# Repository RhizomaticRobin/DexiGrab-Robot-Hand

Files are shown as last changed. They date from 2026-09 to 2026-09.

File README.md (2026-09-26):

# DEXIGRAB

**/ˈdɛk.si.ɡræb/ (DEK-see-grab) - DEXIGRABs (plural): /ˈdɛk.si.ɡræbz/ (DEK-see-grabz)

An advanced, libre-source robot hand with integrated hybrid soft robotics, and soon GelSense-touch capabilities with pretrained sensor fusion RL models

robot hand
robot_hand_back

## Introduction

"What? Another esoteric 3D printed robot hand project that's basically just a toy/puppet/useless gizmo dohicky with 5 string motors? No! There's too many of those already!"

Well, here's where I might change your mind regarding that!

## Features

- **Flexible TPU palm mechanics**, allowing for hybrid soft robotics that allow for actual grasping around curved objects in comparison to current traditional robotic palm mechanics
- 20 motors allowing for **20 DOF hand dexterity**: 4 DOF for each finger and 4 on the thumb (yaw, pitch, base flexion, and a coupled middle/tip flexion). The V6 thumb-pitch motor is being added now.
- Straightforward 3D printing and assembly with **only 5-10 3D printed parts** to be assembled together for more plug-and-play use dynamics
- Mechanics and electronics **entirely constrained** inside the palm, allowing for full end-effector modularity with all current and future robotic manipulators
- Full integration of https://flexitac.github.io as NEW FULLY ENCOMPASSING TOUCH SENSING for the grand cost of... 2 dollars and 59 cents!
- **Universal Robot Attachment** system that can be 3D printed to interface with any robot arm's end effector attachment system
- **Multi-modal sensor fusion** integrating:
  - Intel® RealSense™ Depth Camera D455
  - (https://flexitac.github.io)
  - Arduino Pro Mini for motor encoder data collection

## V6 Hardware Redesign (in progress)

<p>
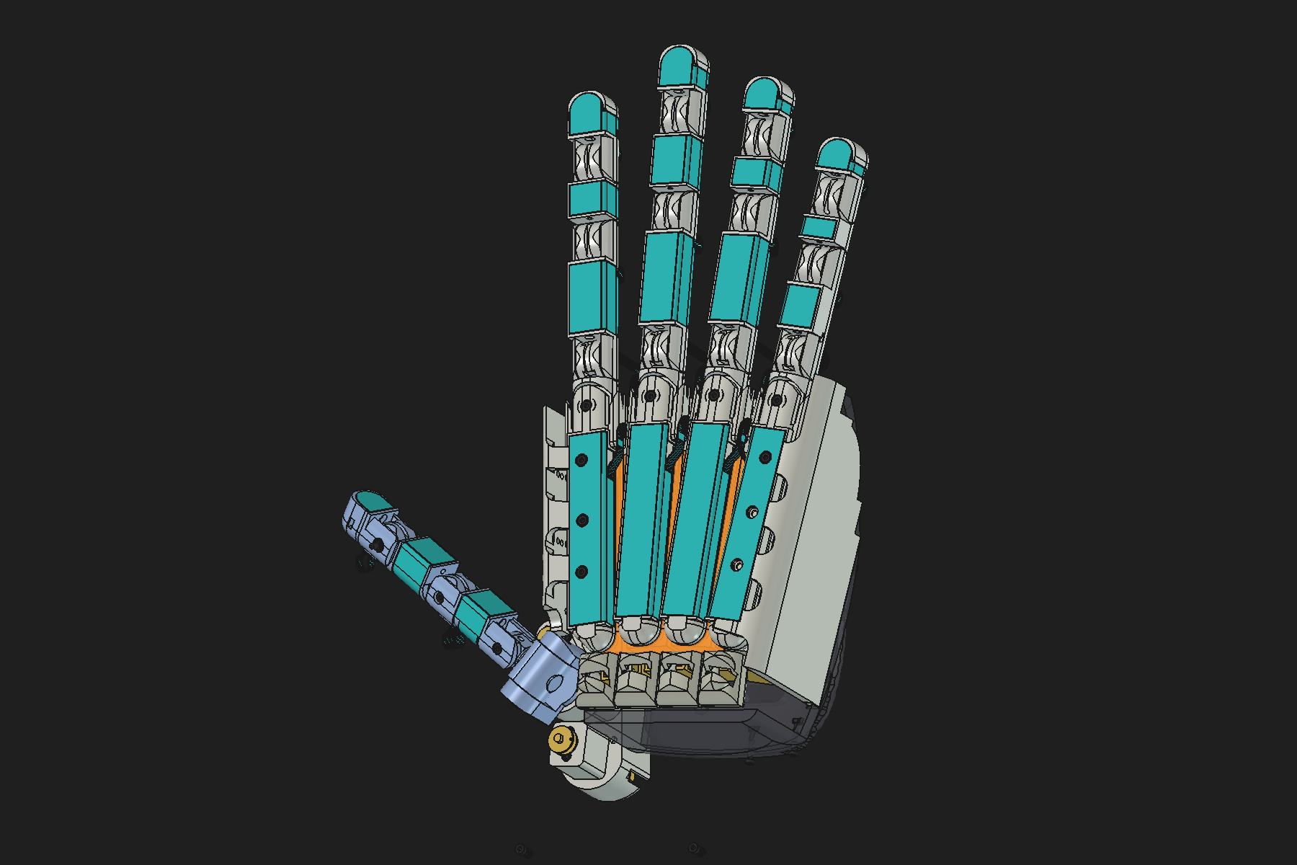
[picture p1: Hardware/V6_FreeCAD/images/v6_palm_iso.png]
V6 palm side

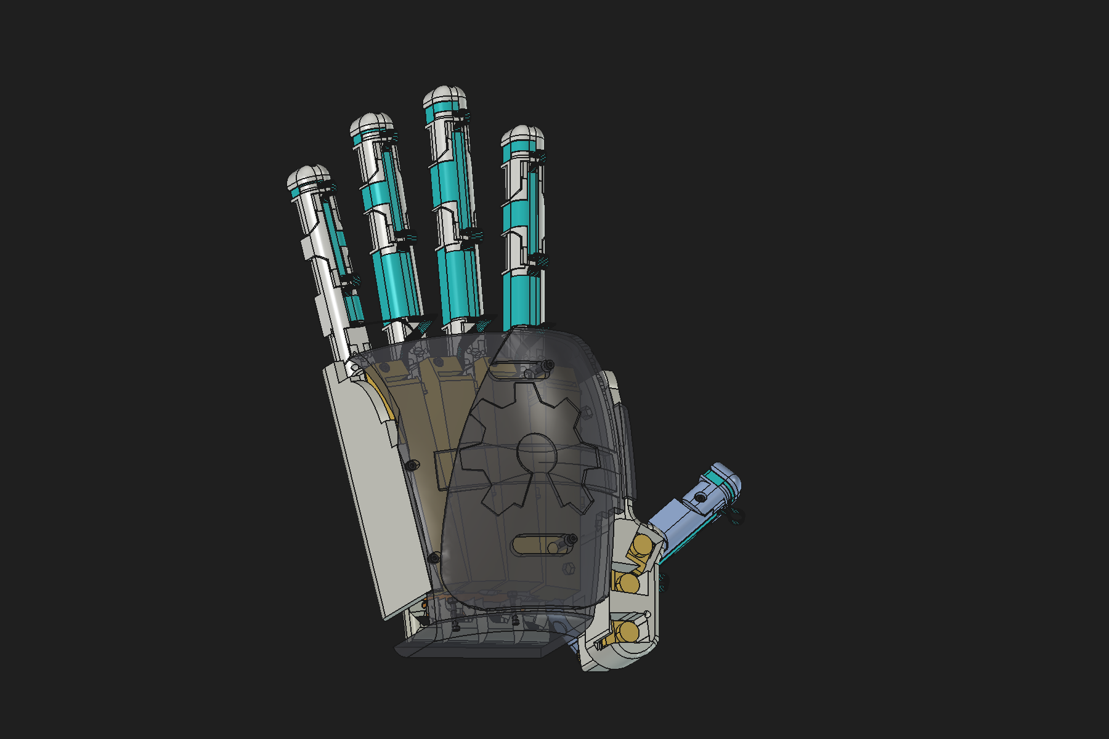
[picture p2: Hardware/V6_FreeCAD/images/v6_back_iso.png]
V6 back side

</p>

V6 is a full engineering pass over the V5 hand, rebuilt as a scripted, fully checked FreeCAD model. See [`Hardware/V6_FreeCAD/`](Hardware/V6_FreeCAD/).

- [x] **Straight N20 gearmotors with encoders** replace the discontinued worm motors, in a 2×2 magazine under each palm bone. There is room for every motor plug.
- [x] **J0 finger joint:** an M2 cap screw and nyloc nut replace the hammered rod that cracked about 35 % of parts.
- [x] **Palm bones:** PLA pillars through the flexible TPU palm, so the bones no longer split.
- [x] **Stronger thumb:**
  - a real yaw bearing, closed gimbal, and steel pins and bolts
  - opposition tuned from Leap Motion recordings
  - thumb motors seated and screwed into their original seat towers
- [x] **Palm shells** with spherical freedom and elastic O-ring retention.
- [x] **Full-hand [FlexiTac](https://flexitac.github.io) touch sensing:** 19 pads, 1421 taxels.
- [x] **Human-proportioned fingers:** Leap Motion bone lengths × 1.25.
- [x] **Fasteners and clearances:**
  - screws and nuts modelled (final validation pending)
  - 0.2 mm clearance wherever parts move
  - the global audit finds no moving pair under 0.2 mm
- [ ] **Electronics:**
  - 10 motor drivers inside the hand
  - a Mini Mega2560 PRO and 2× 6 V NiMH packs in a forearm pod
  - an auto-routed wiring harness
- [ ] **20th motor for thumb pitch**
- [ ] **V6.2:** resting pinky and index splay
- [ ] Final hardware validation and full range-of-motion audit

## AI & Simulation

simulated reach -> grasp -> lift with tactile pads

The simulation work now lives in this repo — see [`Simulation/`](Simulation/):

- **Full physics model of the hand in NVIDIA Newton** (MuJoCo-Warp solver): the flexible
  TPU palm modeled as 8 spring palm bones with 3 closed kinematic loops, 19 finger DOFs,
  self-colliding shells, and **15-pad tactile sensing**
- **Arm-mounted grasp demo** (Franka FR3) with an honest `--check` gate — a pass requires a
  clean approach, multi-pad tactile contact, and a real lift, not a cube wedged in the shell
- **GPU-batched in-hand reorientation RL environment** + self-contained PPO trainer,
  validated at **N=8192 parallel worlds, 0.0% solver divergence, ~47k env-steps/s** on a
  single RTX 5090 — plus the full forensics of the batched-solver NaN failure mode that had
  to be root-caused to get there
- **Honest RL status**: reorientation policies stall for contact-fidelity reasons documented
  in [`Simulation/README.md`](Simulation/README.md), so no pretrained models are published
  yet — that finding is what redirected this project toward engine-level contact-physics
  work, rather than shipping policies from a sim that can't be trusted

## Related Resources

- [L3-F-TOUCH shown](https://youtu.be/ASt3WRFcAxU?si=XV7Dn4dw2RqogxgP)
- [General Concept of touch module](https://youtu.be/qtQ4rK66vlE?si=lcGbKkfz59pFsFFY)
- [Simulation environment to be possibly integrated](https://github.com/facebookresearch/tacto)

## Applications

- Primary use as a **robotic end effector** with advanced grasping capabilities
- Secondary application as a **low-weight and cost-accessible hand for prosthetics design**, especially if built with worm drive gearboxes for human-level gripping strength
- Customizable socket system (hopefully also full copyleft) for any given person

## Project Details

- **<~$250 cost to build**
- **Fully open source hardware and software** under the GPL 3.0 and CERN-OHL pair license :)

## Coming Soon^TM

- Assembly instructions
- Component lists
- Software setup guide
- Simulation integration details
- Attachment system designs

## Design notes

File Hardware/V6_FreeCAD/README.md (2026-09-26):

# DexiGrab V6: FreeCAD redesign (work in progress)

V6 is a full engineering pass over the V5 hand. It keeps the V5 layout and the flexible TPU palm, and fixes what broke or was missing.

The model is built by a scripted FreeCAD pipeline, so every change is reproducible:
- Each workstream (J0 joint, palm pillars, thumb, motors, shells, tactile skin, finger proportions, fasteners) is one Python module that modifies the V5 parts.
- A headless build composes the modules.
- Every result is checked for clearance and range of motion.

<p>
V6 palm side
V6 back side
</p>

**Status (2026-09-26)**

- ✅ Built and verified in the model:
  - straight N20 motors
  - J0 screw joints and palm pillars
  - stronger thumb
  - palm shells
  - FlexiTac tactile skin
  - human-proportioned fingers
  - fasteners (final validation pending)
- ⏳ In progress:
  - electronics, battery pod and wiring harness
  - the 20th motor (thumb pitch)
  - V6.2 resting finger splay
  - final hardware validation and full audit

## Motors and degrees of freedom

| | Joints | Motors | Drive |
|---|---|---|---|
| **Each finger** (×4) | 4: J0 splay, J1 knuckle, J2 middle, J3 tip | 4 | A→J1, B→J2, C→J3 flexor tendons; D→J0 closed tendon loop (both ways). Every joint has its own motor. The fingers straighten on one elastic cord per joint. |
| **Thumb** | 6: R1 yaw, R2 pitch, R3 roll, R4 base flexion, R5 + R6 | 4 | T3 → yaw, direct drive. T4 → pitch, tendon loop *(being added)*. T1 → R4. T2 → R5 + R6, coupled by one tendon. Roll is passive (friction-held, −93…−23°). |
| **Hand** | **22** | **20** | **20 independently controlled DOF** |

The motors are straight (coaxial) N20 gearmotors with 6-pin Hall encoders; V5's worm GM12-N20 is no longer sold. The design assumes 1:298 gearing and 7 PPR, so measure your motors.

## What changed from V5

| V5 problem | V6 |
|---|---|
| J0: a hammered rod that cracked the part about 35 % of the time | M2×16 cap screw and M2 nyloc. The palm lug is thickened to 5 mm, with a flush counterbore, a hex nut pocket and 0.2 mm running gaps. The screw tip passes the nyloc by 3.5 threads. |
| The TPU palm insert splits each palm bone | PLA pillars through holes in the TPU. The TPU is inserted at a print pause, and every palm bone prints as one piece. |
| Weak thumb with a big gap | Real yaw bearing: Ø18 journal plus thrust ring, so the motor carries torque only. Closed gimbal, steel pin and tube at R2, M2 bolts at R4–R6. Flex stack re-clocked for opposition from Leap Motion data: pad-direction error 48.5° → 0.1°. |
| Worm motors discontinued; index and pinky motors had no room for their wires | A 2×2 N20 magazine under each palm bone. Every motor plug faces sideways into free space. |
| Thumb motors | T1 and T2 stand in their V5 seat towers, centred, turned to the seat angle and screwed to a printed floor. T3 direct-drives the yaw. |
| Palm shells | Shell2 rides on a spherical land on Shell1. Studs run through arc slots and are held by silicone O-rings: elastic retention with spherical freedom. |
| No touch sensing | [FlexiTac](https://flexitac.github.io) skin: 19 pads and 1421 taxels at 2 mm pitch. One flex circuit per finger, with slack loops at the joints. |
| Proportions | Fingers re-proportioned to the author's hand (Leap Motion bone lengths × 1.25). |
| Missing hardware | Screws, nuts, washers and heat-set inserts are modelled and placed from per-module requests, and checked by a validator. A final validation pass is pending. |
| Clearances | 0.2 mm per side wherever parts move or fit together. |

<p>
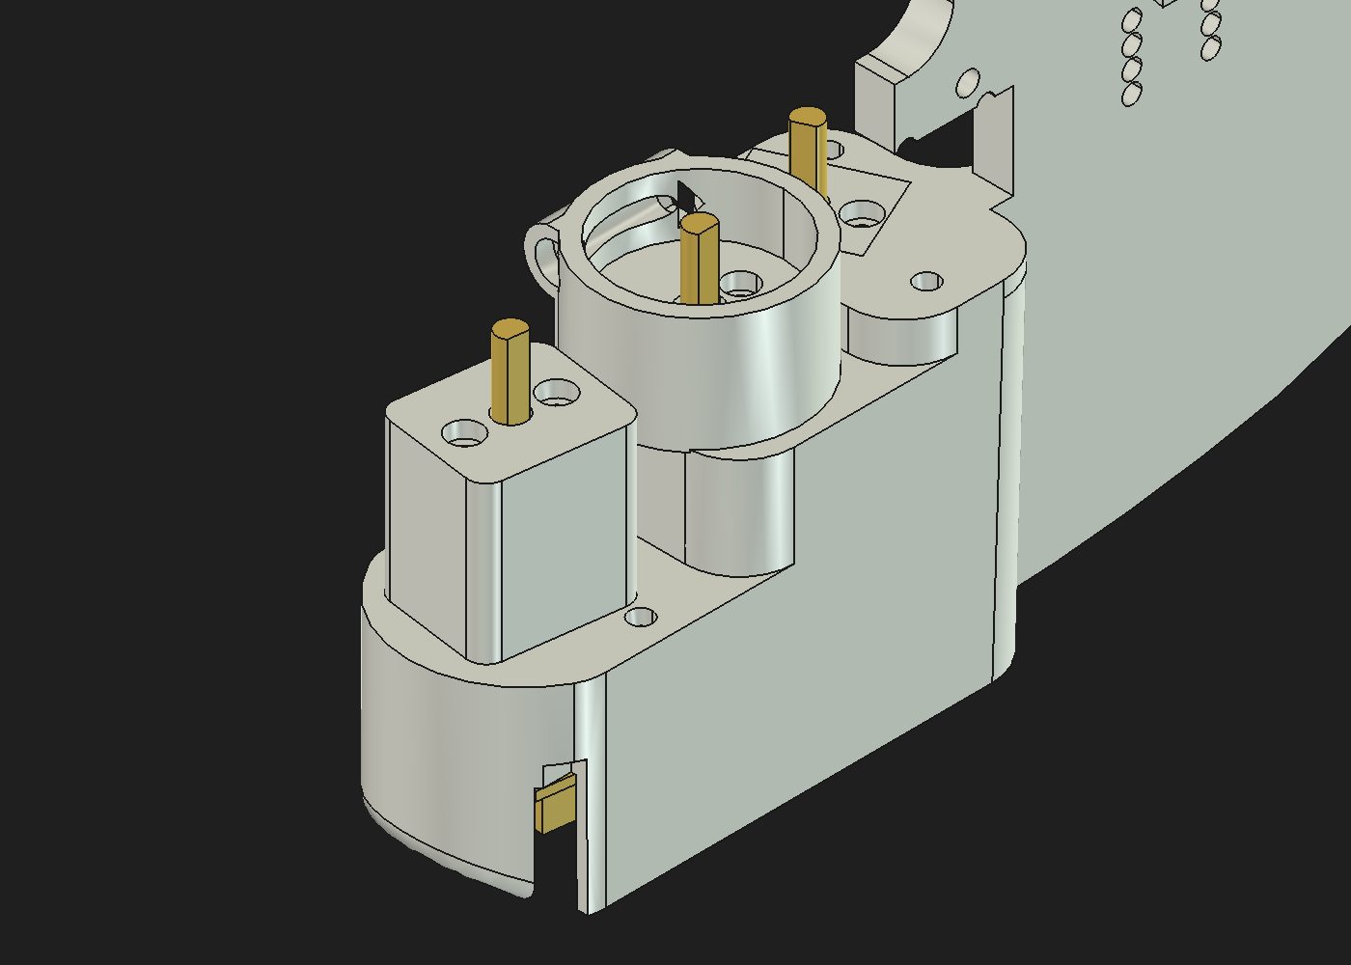
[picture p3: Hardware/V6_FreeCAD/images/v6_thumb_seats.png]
Thumb motor seats: T1 collar, T3 yaw turret, T2 floor

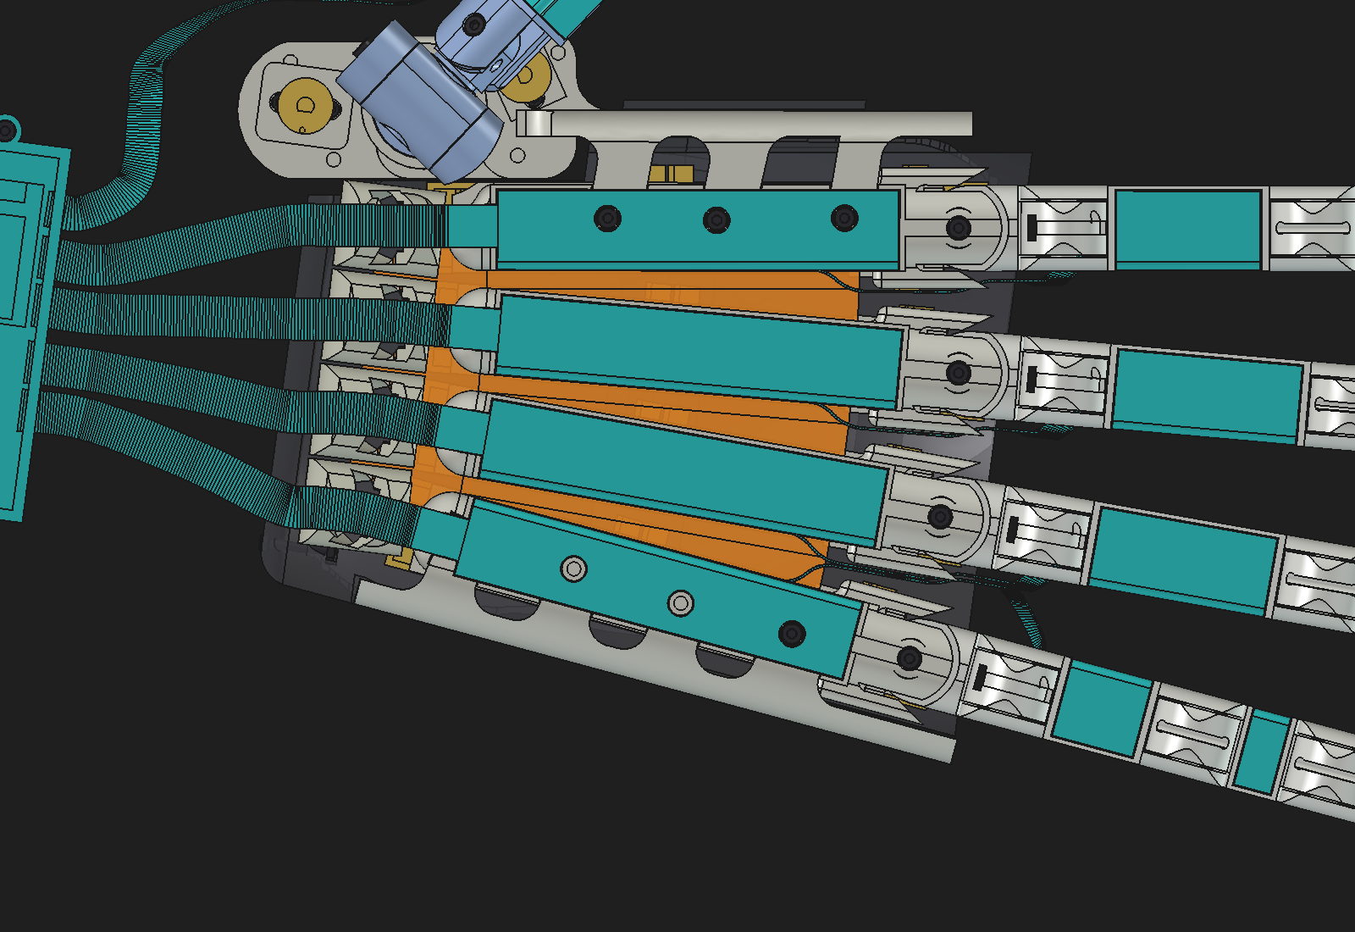
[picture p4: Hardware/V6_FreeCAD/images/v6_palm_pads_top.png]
Palm-side FlexiTac pads

</p>

## Verification highlights

**Global clearance audit**
- Zero moving part pairs are under 0.2 mm.
- The only volume overlaps are intended ones: self-tapping screws in their pilot holes, and heat-set inserts.

**Range-of-motion sweep of all 22 joints**
- Fingers J1–J3 are clear over 0–90°.
- Coupled limits for the firmware:
  - A finger meets its neighbour at about 11° of J0 splay.
  - Thumb yaw is clear on −85…−20° at pitch 0, and on the full −85…+75° at pitch ≤ −45°. The pitch motor makes that usable.

**Thumb**
- All running clearances are ≥ 0.2 mm.
- Index and middle pinch pads meet with gaps of 0.11 mm and 0.06 mm, with no other collisions.

**Motors and tendons**
- No motor or spool overlaps; every plug keep-out is clear.
- Tendon channel walls are ≥ 1.0 mm, and bends are ≥ 3 mm radius.

**Shells**
- 48/48 checks pass.
- A 25-pose roll/tilt sweep shows no collision and no loss of retention.

**Tactile**
- Pads sit 0.2 mm proud with 0.2 mm edge clearance.
- 60 finger poses are clear, and every flex bend is ≥ 3 mm radius.

Details, numbers and open items are in [`freecad/notes/V6_REPORT.md`](freecad/notes/V6_REPORT.md), with one note per workstream in [`freecad/notes/`](freecad/notes/).

## In progress

- **Electronics**
  - 10 dual H-bridge drivers on a deck inside Shell1.
  - An I/O board on cover_back.
  - A forearm pod holding the Mini Mega2560 PRO and the two 6 V 2800 mAh NiMH packs, wired in parallel.
  - An auto-routed harness and wiring tunnels.
- **T4 thumb-pitch motor** (the 20th motor): a tendon loop from a motor fixed in the thumb-side cover to a pulley on the pitch axis. It uses the spare driver channel.
- **V6.2:** a built-in resting splay, pinky outward and index toward the thumb, fitted to Leap Motion data.
- **Final checks:** hardware validation, then the full audit and range-of-motion sweep on the complete build.

## Folder layout

```
Hardware/V6_FreeCAD/
├── freecad/DexiGrab_V6.FCStd   the current V6 model (open it in FreeCAD 1.1)
├── freecad/lib/                one module per workstream: mod_j0, mod_pillars, mod_thumb, mod_actuation,
│                               mod_shells, mod_fixes, mod_tactile, mod_proportions, mod_hardware
│                               (+ n20.py motor model, partkeys.py, v6geom.py)
├── freecad/scripts/            build_v6.py (headless build), gui_load.py / gui_colors.py (load into the GUI),
│                               audit_clearance.py, rom_sweep.py, verify_<topic>.py
├── freecad/notes/              design notes per workstream, V6_REPORT.md, V5_CAD_analysis.md
├── freecad/regions/            motor poses, fastener requests, hardware report, space claims (JSON)
├── freecad/work/shells/bake/   baked Shell2 mesh data read by mod_shells
├── data/                       assembly transforms, joint definitions, V5 CAD analysis tables
├── v5_step/                    V5 part STEP export (pipeline input)
└── images/
```

## Open and rebuild

To just look at the model, open `freecad/DexiGrab_V6.FCStd` in FreeCAD 1.1.

To rebuild it:

1. **Point the scripts at your checkout.** They use absolute paths, which ship as a placeholder:

   ```bash
   cd Hardware/V6_FreeCAD
   python3 - <<'EOF'
   import pathlib
   root = pathlib.Path('.').resolve()
   PH = '/path/to/DexiGrab-Robot-Hand/Hardware/V6_FreeCAD'
   for p in root.rglob('*'):
       if p.is_file() and p.suffix in ('.py', '.sh', '.json', '.md'):
           s = p.read_text()
           if PH in s:
               p.write_text(s.replace(PH, str(root)))
   EOF
   ```

2. **Build every part headless**, which takes about 5 minutes. `freecadcmd` ships with FreeCAD; on macOS it is `/Applications/FreeCAD.app/Contents/Resources/bin/freecadcmd`.

   ```bash
   V6_RUN=1 V6_OUT=$PWD/freecad/work/built.FCStd V6_BREP=$PWD/freecad/build \
       freecadcmd freecad/scripts/build_v6.py
   ```

   `V6_MODULES=j0,pillars,...` selects and orders the modules; the default is all of them.

3. **Load the build into the GUI.** Open `freecad/DexiGrab_V6.FCStd`, then run `freecad/scripts/gui_load.py` and `freecad/scripts/gui_colors.py` from the Python console.

4. **Check it.** Each script takes the built file as `V6_IN=freecad/work/built.FCStd`:
   - `freecad/scripts/audit_clearance.py`
   - `freecad/scripts/rom_sweep.py`
   - `freecad/scripts/verify_<topic>.py`

The source parts are the V5 "simulacra" assembly, exported from Onshape with its exact occurrence transforms (`data/top_assembly_definition.json`).

## Licences

- The V6 files follow this repository's licences: CERN-OHL-W v2 for hardware and GPL-3.0 for software.
- The tactile skin reuses [FlexiTac](https://flexitac.github.io)'s readout board and firmware unchanged. FlexiTac is CC BY-NC 4.0 (non-commercial, attribution required), and that applies to any FlexiTac-derived parts you build.

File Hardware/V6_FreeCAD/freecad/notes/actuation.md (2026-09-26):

# Actuation (V6): straight N20 gearmotors, motor magazines, spools and tendons

Module `lib/mod_actuation.py`. Check `scripts/verify_actuation.py` (results in section 9). Published data:
`regions/actuation_motors.json` (world pose of all 19 motors incl. T3 from mod_thumb), `regions/actuation.json`
(claimed regions), `regions/fasteners_actuation.json`. Test build: `V6_MODULES=j0,pillars,thumb,actuation`
(about 3 min, one freecadcmd), then `freecadcmd scripts/verify_actuation.py`.

## 1. Why the V5 seats could not be reused

The V5 seats hold a worm GM12-N20 inclined 30.7° with its can in the palm bone and its perpendicular output shaft
(and the Ø21 pulley) hanging into the cavity. A straight N20 puts the spool on the motor axis, so:

- **In the old seat, the encoder end sits inside the bone.** The 6-pin plug mates along the axis, so its 8 mm plug
  space would point up through the palm face. That is exactly the "no room for the wiring" the user saw on the
  index and pinky; on the middle and ring it only looked better because the cable could escape sideways.
- **Reversed in the old seat**, the spool ends up inside the bone and its tendon leaves the spool at 60° down.
- **Vertical motors** (axis along the old worm shaft) need about 50 mm of depth each and fill the whole bowl.

## 2. Layout chosen: one 2×2 magazine under every palm bone

Each finger's four motors lie **along its own palm bone** (bone-local x), in two tiers:

| motor | tier | joint | spool (tendon axis radius) | notes |
|---|---|---|---|---|
| A | 1 (under the bone), front | **J1** flexor | small, r 3.75 | encoder toward the fingertips |
| B | 1, rear | **J2** flexor | small, r 3.75 | |
| C | 2 (under tier 1), front | **J3** flexor | big, r 5.65 | index C: tab turned to −z |
| D | 2, rear | **J0** loop (2 grooves) | big, r 5.65 | |

- **Why per finger:** the palm bones float on TPU (the palm arches). With every motor, spool and guide on the bone it
  drives, the tendon path from spool to finger never changes when the palm deforms. It also keeps the side walls free
  for the driver boards.
- **Orientation:** motor axis along the bone, flats vertical, encoder end toward the fingertips, PCB tab and plug toward
  bone-local +z (the thumb side). The index C motor has its tab toward −z because its +z plug space touched Shell1.
  - Every plug therefore points into the open inter-finger gap beside the magazine, 6–11 mm off the motor axis. Its
    cable drops straight down to the harness.
  - The adjacent finger's magazine is on the other side of that gap, and no two tabs face each other in the same gap.
- **Magazine:** PLA fused to the underside of the palm bone. It is printed as part of the bone (section 8).
  - Bays open downward. Each gearbox sits between two 0.6/0.8 mm **fork ribs** (a U-slot for the boss, and the can
    profile behind), which fix it axially and against the motor torque.
  - Two 1 mm **side lanes** run beside tier 1, and there is a 1.7 mm wall with the J0 tunnels in it. Roof strips
    (y 3.6–5.2, cut round the TPU peg holes) close the tunnels where the bone's rounded corners are thin (pinky).
  - An **under-J0 guide block** sits in front of motor A, below the J0 nut. A descent boss over A's magnet carries the
    A/B drops.
  - Near J0 the magazine stays out of the base-bone tongue's ±15° sweep: the slot floor is at y 4.7 (the j0 back-lug
    face), the cheeks under the wing channels are at |z| ≥ 6.95 for x > 83.1, and only the unused rear of the slot
    (x 81.5–83.2) is filled.
- **Tray:** a new part per finger (`actuation_tray_<finger>`).
  - It holds tier 2 in its own fork ribs, and its shelves carry the tier-1 gearboxes (0.2 mm gaps).
  - It hooks into a groove in the rear wall of the magazine and is held at the front by **1× M2×12 SHCS + M2 hex
    nut**. The nut is side-loaded into the guide block, below its tendon channels, and the head is recessed 6 mm
    in the tray.
  - The tray's front-bottom edge is chamfered to clear Shell1.
- **Old worm seats are filled.** This covers the troughs and the palm-face crescents, inside the 15×15 envelope for
  x 7.8–71.2. The fill stops **exactly at the TPU insert layer (y 0.5 and 1.1)**. It leaves every TPU peg hole and the
  index bracket-screw keep-outs open.
  - The TPU motor windows inside the layer are **left empty**. They are pillars' to fill if they want large pillars
    there.
  - The pillars stay ≥ 6.4 mm from every motor envelope, according to pillars.
- **Depth:** tier 1 is at world z −8.2 … −20.2, tier 2 at −21.6 … −33.6, and the tray floor bottom at about −35.6.
- **Bone-local x positions of the gearbox faces:** A 55.0, B 14.0, C 53.5, D 9.0. The motors run from x −1.8 (D shaft
  tip) to 85.0 (A magnet), and the tray from −3.6 to 94.4.
  - The magazines sit between world x ≈ −165 (the D shaft tip) and the knuckles. They stay behind the J0 nut
    keep-out and the metacarpal's J1 sweep.

## 3. Motor, spools, torque and speed

**Assumed motor:** 6 V N20, **1:298** (about 100 rpm no-load at 6 V), with a magnetic Hall encoder (7 PPR per channel).
- Stall torque ≈ 0.4 N·m; safe continuous ≈ 0.18 N·m (gearbox-limited).
- These are catalogue values. Measure the real ratio and stall current with BUILD_PLAN 1.6–1.8.
- 1:298 was chosen because the spur gearbox is back-drivable, unlike the V5 worms, and the highest common ratio gives
  the most holding friction and torque. Speed is still ample.

| spool | tendon radius | tendon force (continuous / stall) | tendon speed |
|---|---|---|---|
| small (A, B, T1, T2) | 3.75 mm (groove floor Ø7.0, flanges Ø9.8) | 48 N / 107 N | 39 mm/s |
| big (C, D) | 5.65 mm (floor Ø10.8, flanges Ø13.2) | 32 N / 71 N | 59 mm/s |

The groove radius is a trade-off:
- **Torque:** smaller is better.
- **Hub wall:** the hub needs at least 1.75 mm of wall around the Ø3 D-shaft, so the minimum floor radius is 3.25 mm.
- **Bend ratio:** D/d = 15 for 0.5 mm line.
- **Excursion:** the J3 flexor needs 33 mm, which is 0.9 turn on the big spool; the 2.4 mm groove holds about 4 turns.

Tier 2 needs the big radius so that its tendons clear tier 1 in the side lanes. It therefore drives the two
lowest-load joints, J3 and J0.

Resulting joint capability (continuous, no-load speed):

| joint | moment arm | torque | speed |
|---|---|---|---|
| J1 | 6.65 mm (tendon in a groove over the J1 head, constant) | 0.32 N·m | 336 °/s |
| J2 | 4.7 → 8.8 mm (open-roof knuckle, grows with flexion) | 0.23 → 0.42 N·m | 475 → 255 °/s |
| J3 | 4.7 → 8.8 mm | 0.15 → 0.28 N·m | 720 → 385 °/s |
| J0 | about 11 mm (lateral wing channels, antagonistic) | 0.35 N·m | 310 °/s |

At the continuous rating that is roughly 4–5 N of fingertip force with the finger straight, and more when the finger
is curled.

**Encoder:** 8344 counts per spool turn (7 × 4 × 298). That is 0.024° of J1 per count, or about 0.05° of J3.

**D-bore fit:** Ø3.0 nominal with the flat 1.0 mm from the axis, zero allowance on purpose. FDM holes print about
0.1 mm small, so the spool presses on.
- Torque is carried by the flat (form lock), not by friction.
- The flat contact stress at 0.18 N·m is about 14 MPa, and about 32 MPa at stall, against about 60 MPa for PLA.
- If the spool is too tight, ream it with a 3.0 mm drill. Add a drop of CA only if it walks off the shaft.
- A set screw does not fit: the smallest screw in the kit is M2×5, whose head would stand beyond the flange.

**Tendon anchor on the spool:** an axial Ø1.0 hole through the outer flange of each groove. The tendon is knotted
behind it.

## 4. Flexor-only drive for J1–J3, antagonistic loop for J0

**Bidirectional loops on J1–J3 are not usable with this knuckle geometry.**
- The back side of every knuckle is square: it is the hyperextension stop.
- An extensor through the V5 back channel (z −4.6) therefore lengthens by 12.3 mm over 90°, while the flexor shortens
  by 10.4–11.2 mm.
- A loop gains about 1–2 mm per joint, which is about 5 mm across J1–J3 for the J3 loop. UHMWPE stretches about 3 %,
  so the loop would over-tension and pull the anchors out.

**So each joint gets one flexor, and extension is passive.**
- Use one elastic per joint through the V5 back channels (z −4.6, added to every bone). A suggested cord is 1 mm
  silicone or latex, knotted, stiffer toward the palm: J1 > J2 > J3, so every flexor stays taut.
- Joint angles are set by the flexor lengths through the coupling matrix: flexor k shortens by the sum of its moment
  arms over the joints it crosses.

**J0 uses one spool with two grooves.** Its two ends run in mirror-image paths to the lateral wings. The loop length
changes only to second order, less than 0.3 mm at ±15°.

## 5. Tendon routing (0.5 mm braided UHMWPE, channels Ø1.2, bends R ≥ 3 except where stated)

**Palm bone and magazine (bone-local):**
- **A and B** rise from their spools through bend bosses (R 3) into two lanes in the bone's back half, at y 5.8 and
  z ∓1.6. The lanes run below the pillars and TPU pegs with at least 1 mm of wall.
- At x ≈ 81–88 they descend through the filled rear of the J0 slot and the boss over A's magnet. They pass beside the
  J0 nut, 4.3 mm off the centre plane, drop through the guide-block legs, and turn in under the nut.
- **C** rises beside tier 1 in the −z side lane, at y 14.0, and enters the guide block at the front, below the A/B
  drops.
- **The J0 axis is crossed underneath.** The guide exit is 4.3 mm in front of the J0 axis and the base-bone entry is
  12.8 mm in front, so the flexor length changes by less than 0.2 mm at ±15° of abduction. This is decoupled without
  touching the M2 J0 screw, which occupies the axis.
- **D (J0 loop):** the two ends rise at z ±5.65 and jog out into tunnels in the magazine wall (y 5.9, z ±6.3; y 6.8 under the TPU wrist-plate
  pocket for x < 9.5). They run forward to x 71.2, then ramp (via x 74.5, y 3.9) into the existing V5 lateral wing
  channels (Ø1.5), 20 % of the way along. They exit at the wing notches, ±10.5 mm lateral and 5.4 mm in front of the
  J0 axis.
  - The V5 wing channel is kept where V5 put it. Over x 82.5–83.5 it is already open into the J0 tongue slot in the
    j0 input (section 10).

**Base bone:**
- The three flexors enter from below at base-local x 13, the V5 connector position, 5.5 mm behind the J1 bore.
- They rise in a 1.4 × 4.4 slot and wrap the J1 head in a groove (floor R 6.4, 2.4 wide) down to the metacarpal's
  clevis floor.
- The J0 loop ends go to two knot anchors: a lateral Ø1.2 through-hole at x 16.8 and z −2, with Ø2.6 knot pockets
  from below at y ±4.4.

**Finger bones.** The same features go on the thumb's metacarpal, proximal and distal (mod_thumb's new keys).
- **The V5 Ø2 channels** are added from `data/sw_bone_channels.csv` (cut at Ø2.1 so they do not coincide with
  existing ones). This covers the metacarpal and pinky metacarpal, and all proximals and the distal at z +4.7/−4.6.
  The distal also gets its seven tip channels.
- **The V5 distal M1.6 anchor** is taken from `sw_instances.csv` (Mirrorm1_*): a Ø3.84 counterbore from the tip, a
  Ø2.1 hole x 5.3–13.3, an M1.6 nut pocket at x 6.5–8.3, and the side slot for the nut.
- **Found and fixed: the V5 palm channels reverse the flexor.**
  - The V5 channels run through the knuckle tongues past the joint axis. At J1 and J2 the flexor's line of action then
    crosses the axis after about 8° of flexion and the "flexor" extends the joint.
  - Fix: at J2 and J3 the channel roof is opened (a 1.6 mm slot down to z 4.0) from the tongue end to 7.7 mm past the
    axis. The effective exits are then the two clevis floors, ±7.7 mm from the axis.
  - The moment arm now grows from 4.7 to 8.8 mm over 90°, and the reversal angle is 117°.
  - At J1 the tendon wraps the head (above).
- **Knot pockets** (Ø3 from the palm face, x 19) anchor the J1 flexor in the metacarpal and the J2 flexor in the
  proximal. The J3 flexor ends at the distal's M1.6 clamp. Channel entries at the clevis floors are flared (Ø4 → Ø2.1).

**Thumb.**
- T1 (R4 flexor, anchored in the thumb metacarpal's knot pocket) and T2 (R5 + R6 flexor, anchored at the thumb
  distal's M1.6 clamp) stand in their V5 seat towers on cover3. Each tower has a 13.0 × 10.5 gearbox pocket, turned
  at its own angle.
- **Re-seated (orchestrator, 2026-09-26).** The first version stood T1/T2 square to the world axes, about 0.4 mm off
  their pocket centres. T1 floated 14 mm above its tower with no floor, and T2's floor and M1.6 holes fell inside the
  V5 pocket's open top. Now:
  - **T1** is centred on its pocket at (−186.02, 21.09) and turned −7.56°, gearbox face at z −24.2. Its tower is
    extended by a collar (pocket + 1.6 wall, R2 corners) from the tower top at z −38.6 to the floor top at z −21.4.
  - **T2** is centred at (−147.93, 26.52) and turned −65.56°, face at −25.8. The tab and plug point toward T3
    (0.3 mm to T3's body), so they stay inside cover3's outline. Turned the other way, the plug would break through
    the outer wall. The pocket's open top is filled from the face up to the tower top at z −23.1: that is its floor.
- The shaft stays below z −15.0 and within r 7.1, per the thumb agent.
- Both have their shaft up, the spool 2 mm out on the shaft above a 2.8 mm floor, and the gearbox face screwed with
  the N20's own 2× M1.6×3 SHCS. Each head sits in a Ø3.6 × 1.8 counterbore with 0.8 mm of floor under it. The spool
  well and tendon window keep their world orientation, so the tendon hand-off is unchanged.
- Their tendons leave the spools horizontally, at z ≈ −17 / −18.8.
- **Hand-off:** these tendons go to the thumb agent's Ø2 path along R2 (the steel tube), the roll-shaft cross holes and
  the ±15° barrel slots. The segment from the spools up to the R2 tube is **not modelled**: see open questions.

## 6. Motor / joint map for the firmware

`wind_sense` is the spool rotation, right-handed about the motor's +X (toward the encoder), that actuates the joint:
it winds the flexor in, or for D it turns J0 toward +Y world (the thumb side). The motor lead polarity that produces it
has to be recorded per channel on the bench, because it depends on the M1/M2 wiring. Channel numbers are a proposal:
the electronics agent owns the driver assignment. The same map is machine-readable in `regions/actuation_motors.json`
(`seat`, `joint`, `channel_proposal`, `wind_sense`, `spool_tendon_radius_mm`, `tendon_anchor`, and the world pose,
connector and plug keep-out of every motor).

| ch | seat | finger / joint | spool r | wind_sense | tendon anchor |
|---|---|---|---|---|---|
| 0 | ID | index J0 (loop) | 5.65 | −1 | base-bone side knots |
| 1 | IA | index J1 flexor | 3.75 | +1 | metacarpal knot pocket |
| 2 | IB | index J2 flexor | 3.75 | −1 | proximal knot pocket |
| 3 | IC | index J3 flexor | 5.65 | +1 | distal M1.6 clamp |
| 4–7 | MD, MA, MB, MC | middle J0, J1, J2, J3 | same | same | same |
| 8–11 | RD, RA, RB, RC | ring J0, J1, J2, J3 | same | same | same |
| 12–15 | PD, PA, PB, PC | pinky J0, J1, J2, J3 | same | same | same |
| 16 | T1 | thumb R4 flexor | 3.75 | +1 | thumb metacarpal knot pocket |
| 17 | T2 | thumb R5+R6 flexor | 3.75 | −1 | thumb distal M1.6 clamp |
| 18 | T3 | thumb R1 yaw, direct drive | none | n/a | mod_thumb coupler |

**Coupling.** With θ in rad, the flexor lengths are:
- L_A = L_A0 − 6.65·θ1
- L_B = L_B0 − 6.65·θ1 − r2(θ2)·θ2
- L_C = L_C0 − 6.65·θ1 − r2·θ2 − r3·θ3

where r2 and r3 grow from 4.7 to 8.8 mm with flexion (chord geometry, `tendon_paths` + the knuckle slots). J0 couples
into the flexors by less than 0.2 mm.

## 7. Tendon lengths and excursions (index; the others are within a few mm)

| tendon | path (spool → anchor) | approx. length | excursion for 0 → 90° | spool turn |
|---|---|---|---|---|
| A (J1) | palm 55 + under-J0 10 + base 24 + metacarpal 4 | 93 mm | 10.4 mm (J1) | 159° |
| B (J2) | palm 96 + 10 + 24 + metacarpal 17 + J2 span 15 + proximal 4 | 166 mm | 21.6 mm (J1 + J2) | 330° |
| C (J3) | palm 64 + 10 + 24 + 17 + 15 + proximal 26 + J3 span 15 + distal 16 | 187 mm | 32.8 mm (J1 + J2 + J3) | 333° |
| D ± (J0) | riser 21 + tunnel 66 + ramp 8 + wing 17 + to knot 4 | ≈ 116 mm each | ±2.9 mm (±15°) | ±29° |
| T1 / T2 | spool → R2 tube → gimbal → thumb | not modelled past the spool | R4: 10.4 mm; R5+R6: 22.4 mm | — |

## 8. Print and assembly notes

**Palm bones: print back side down, as pillars asked.** The flat bottom of the magazine (bone-local y 20.1) is on the
bed, so the magazine needs no other orientation.
- With the magazine the bone is 12.6 mm taller, so **the TPU pause moves to 19.6 mm** (it was 7.0 for the bare bone).
- Its TPU plane no longer matches the wrist segments' 8.5 mm. Print the palm bones alone, or on one plate with the
  wrist segments using two pauses (8.5 and 19.6 mm).
- The bays are open toward the bed and their ceilings bridge 12.4 mm. The fork ribs and the guide block stand on the
  bed.
- Use tree supports only under the blocks that hang from the bay ceilings: the two bend bosses and the descent boss
  over A's magnet. They are inside the open bays, so the supports come out easily. The rear corner ledges (1 mm) need
  none.

**Trays:** print floor down. No supports are needed.

**Spools:** print with the axis vertical, at 0.1 mm layers.

**Assembly:**
1. Press the spools on (the D-flat toward the tab), then tie the tendons through the flange holes.
2. Pre-thread each tendon from the spool along its channel before seating the motor. Channel order along the bone: A/B
   up into the bone lanes and out through the guide; C up the −z lane into the guide; D up through the rear risers into
   the tunnels, then the wing channels.
3. Seat A and B in the upper bays, with the gearbox between the forks and the tab through the +z window.
4. Drop C and D into the tray.
5. Hook the tray's tongue into the rear groove, swing it up, and fit the front M2×12. The nut is slid in from −z before
   the tray goes on.
6. Plug the cables before closing. The plugs are reachable through the side windows.

**T1 / T2:** insert from below (the pockets are turned to the seat angles; T2's tab faces T3), then screw the gearbox face to the floor with 2× M1.6×3 SHCS through the spool well. Press
the spool on last.

## 9. Verification (`scripts/verify_actuation.py` on `work/actuation/test.FCStd`)

Build: master `DexiGrab_V6.FCStd` with `V6_MODULES=j0,pillars,thumb,actuation` (about 4 min, one freecadcmd). The
check runs in parts (`V6_SECT=235`, `46`, `6`) to keep each run under 5 min.

| check | result |
|---|---|
| 1. validity | all 23 changed or new parts are valid single solids: 4 palm bones, base bone, cover3, 3 thumb bones, 6 finger bones, N20, 3 spools, 4 trays |
| 2. motors, spools and trays vs every part | 0 overlaps, minimum gap 0.200 mm (to the magazines, trays and cover3) |
| 3. plug keep-outs (8 mm, 18 motors) | 0 blocked |
| 4. ROM, J0 ±15° | base bone ≥ 0.200 mm from the magazine, cheeks and slot fill (0.2 mm is j0's own tongue/back-lug gap) |
| 4. ROM, J1 0–90° | metacarpal, proximal and distal: nothing within 1 mm of the magazines, trays, motors or spools |
| 5. T1/T2 vs thumb yaw −70…+75° | minimum 0.40 mm (first_thumb_hinge at +15° vs Spool_T1) |
| 6. channel walls (need ≥ 1.0 mm) | A lanes 1.09, B lanes 1.02, C guide 1.50, D tunnels 1.00 mm, the same on all four fingers |
| 6. V5 wing channels (information only) | 0.00: open into the J0 slot at x 82.5–83.5, the same in the j0 input |

The wall check measures from each channel's axis to the nearest face that is not part of that tendon's own channel
(risers included). The wing channels are measured by ray marching, because the V5 hole and the re-cut leave slivers
under 0.15 mm.

## 10. Open questions and conflicts

1. **Depth versus battery and harness.** The magazines need the space down to world z ≈ −35.6 (the tray floors) under
   all four palm bones. Electronics' draft has the harness layer at −32 … −22 and the battery-case top at −31. They
   were drafted against the old inclined-seat poses. Both have to move below −36, or the battery goes elsewhere.
   - 2 stacked 5×AA packs are 29 mm thick. From −36 down to the bowl's bottom (−64) leaves 28 mm at the centre, so the
     case must bulge through Shell1 (V5 did that too) or move out of the palm.
2. **Rear end.** The D shaft tips reach bone-local x −1.8, which is world x ≈ −163 (index) … −168 (pinky), at z −28.
   That is inside the draft Mega box (x −187 … −158); the board itself, on cover_back, is clear.
3. **The T1/T2 tendon path** from the spools (z ≈ −17) up to the thumb agent's R2 tube (z −0.5, swinging with yaw) is
   not modelled.
   - A fixed guide near R1 (for example an eyelet on the turret rim) would give the least yaw coupling.
   - Yaw couples into both thumb flexors, which the firmware can compensate using T3's encoder.
4. The **extension elastics** are not modelled: section 4 gives the recommendation.
5. **Motor data** (ratio, stall torque, encoder PPR) are assumptions. Measure them (BUILD_PLAN 1.6–1.8) before tuning
   the gains.
6. **The 0.5 mm line is an assumption** (braided UHMWPE, about 40 kg). Thicker line needs Ø1.4 channels, a 0.1 mm
   change of `TR`.
7. **V5 lateral wing channels (J0 loop).**
   - The Ø1.5 channel from V5 runs 0–0.65 mm from the side wall of the J0 tongue slot. It opens into the slot over
     x 82.5–83.5, 0.4 mm behind the tongue's rear end. This is the same in the j0 input, and it was kept so the V5 exit
     notches still match.
   - The taut tendon stays about 0.4 mm inside the bore line, so the tongue should not touch it. Check it on the bench.
   - If it frays, move the wing channel 0.7 mm outward (fill the V5 hole first) or glue in a Ø1.5/1.0 PTFE sleeve.
8. **Cables and the Shell2/cover3 seam.**
   - T1/T2 plug downward (−Z) into the cavity under cover3.
   - Their cables must run inside the cavity to the harness, never through the moving seam (shells' rule).
   - The finger motors' cables drop from the +z windows (−z for index C) straight down beside each magazine.

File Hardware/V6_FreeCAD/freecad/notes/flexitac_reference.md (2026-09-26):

# FlexiTac reference (collected by the orchestrator on 2026-09-25)

**Sources**
- Project page: https://flexitac.github.io
- Paper: Huang & Li, Columbia, arXiv:2604.28156
- Hardware repo: github.com/FlexiTac/FlexiTac_Hardware_Repo (firmware `32_16_fast.ino`, host `fast_32_16.py`)
- Tutorial (Google Doc): exported to `work/tactile/ref/tutorial.txt`
- Local copies of all of the above: `work/tactile/ref/`
- **License: CC BY-NC 4.0** (non-commercial)

## Sensor (V2, current)
- Two FPCs, top and bottom: flex PCB **0.2 mm**, gold fingers 0.3 mm thick. The top FPC carries the row electrodes and the bottom the column electrodes, or the other way round.
- Piezoresistive film between the FPCs: **Velostat/Linqstat** (Adafruit 1361, about 0.1 mm).
- Each FPC is laminated with **adhesive laminating sheets**, and the edges are **sealed with polyimide (Kapton) tape**.
- The whole stack is roughly 0.6–0.8 mm; the page gives no exact figure. Budget **0.8 mm**, plus an optional protective skin.
- Standard V2 piece: **32 × 12 taxels at 2 mm pitch**, about 64 × 24 mm active, about $2.50 per pair at 100 units.
- V1 was 16 × 16 at 3 mm pitch.
- Custom shapes are made by designing your own top and bottom FPC Gerbers. The FlexiTac pitch is 2 mm.
- Durability: about 1 year, and "thousands of demonstrations".

## Readout
- **"Reading Board 32x16"**: an Arduino Nano (ATmega328), **1 analog mux** (16 rows, 4 select pins plus inhibit) and **4 shift registers** (32 columns, data plus clock). All taxels go through the single ADC input A0, with a 10-bit reading reduced to 8 bits.
- **0.5 mm-pitch FFC connectors**: 16-pin for the rows and 32-pin for the columns. The FFC extenders are 20-pin and 40-pin Adafruit parts, or bulkier AliExpress easy-install ones.
- One board reads **one 16 × 32 matrix (512 taxels)**. A "Reading Board 32x32" (1024 taxels) also exists, marked as a development board.
- Output is USB serial (mini-USB on the Nano) at **2,000,000 baud**. Each frame is the header `0xAA 0x55` followed by 512 bytes, one byte per taxel.
- Host side: PyPI `flexitac` (`FlexiTacSensor`), with baseline subtraction, a threshold and normalisation.
- Board dimensions are not published: the Nano is 18 × 45 mm, and the reading board is roughly Nano-sized plus its FFC connectors. Model it as about 50 × 25 × 15 mm with the Nano plugged in, and say that this is an assumption.

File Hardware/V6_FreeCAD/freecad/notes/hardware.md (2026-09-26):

# Hardware (topic `hardware`): screws, nuts, washers, inserts

Files: `lib/mod_hardware.py` (new_parts, instances), `scripts/verify_hardware.py`, `regions/hardware.json`
(claimed space), `regions/hardware_report.json` (validation report; rewritten by every build and by verify).

## What the module does

- **Library** (`new_parts()`, keys `hardware_*`, all single valid solids, identity placement, no helical faces).
  Seat frame: origin = seat point (underside of the head / bearing face of nut or washer / top of insert),
  +Z from head to tip; screws occupy z -k..L, nuts z 0..h with flats normal to local X.
  - M2 SHCS ISO 4762 (dk 3.8, k 2.0, 1.5 hex): head taken from the `sw_source` STEP (real socket, 1.125 deep)
    on a plain Ø2.0 shank with the STEP's tip chamfer. Base set 5/8/10/12/14/16; any STEP length
    (3–30) is built on demand.
  - M2 hex nut ISO 4032 (s 4.0, m 1.6): STEP body, helical thread replaced by a plain Ø2.02 bore.
  - M2 nyloc DIN 985 (s 4.0, h 2.8; supplier tables give 2.8–3.0, m ≥ 1.6), parametric.
  - M2 washer ISO 7089 2.2/5.0/**0.3** (the sw_source washer STEP is 0.4 thick: not ISO 7089).
  - M1.6 SHCS ISO 4762 (dk 3.0, k 1.6, 1.5 hex) 3/5 (+ any length on demand); M1.6 nut ISO 4032 (s 3.2, m 1.3).
  - On request only: `M2 insert` (generic heat-set M2 × 3, OD 3.2, hole Ø3.0) and `M2 long insert`
    (ruthex RX-M2x4, OD 3.6 × 4, hole Ø3.2); M1.6 washer.
- **Placement** (`instances()`, group `Hardware`, links `HW_<id>_screw|nut|washer_*`):
  1. J0 pivots (4 × M2×16 + M2 nyloc) from `mod_j0`'s stack, placed with the palm-bone links.
  2. V5 sites (`data/sw_fasteners_onshape.csv`) whose holes exist in the built geometry.
  3. Every entry of every `regions/fasteners_*.json`, read at build time (unreadable/partial files are
     retried, then skipped and reported; bad entries are rejected with the reason).
  Each joint is snapped onto its modelled bore (≤ 0.35 mm, 2°), put on the real seat face, its nut face is
  inferred (first seat where the nut fits, flats aligned to the pocket) and it is validated: clearance hole
  ≥ d+0.4, head space ≥ dk+0.4, nut pocket ≥ AF+0.4, head and nut seated on material, thread engagement,
  "joins ≥ 2 parts", collisions with every placed part. Duplicates in one hole: J0 > request > V5.
  Failed joints are coloured red and listed in the report.
- **Request extras** (beyond the README format): `name`; `nut` `"M2 hex"|"M2 nyloc"|"M2 insert"|"M2 long insert"|null`;
  `nut_offset` (seat → face the nut/insert bears on; inferred when absent); `washer` `"head"|"nut"|"both"`;
  `frame: "local"` with `part` (one joint per instance of that part key) or `instance` (link label).

## J0 pivot (requirement 9)

Stack along the axis, z from the head seat (identical on all four fingers, measured on the build):

| z (mm) | item |
|---|---|
| −2.0 … 0 | M2×16 head in the Ø4.2 × 2.2 counterbore (head top 0.2 below the palm-side face) |
| 0 … 2.8 | palm-side lug (Ø2.4) |
| 2.8 … 3.0 | 0.2 gap |
| 3.0 … 9.8 | Base Bone 1 tongue (Ø2.4), the finger turns on the screw |
| 9.8 … 10.0 | 0.2 gap |
| 10.0 … 11.8 | back lug (Ø2.4) |
| 11.8 … 14.6 | M2 nyloc on the 4.4 AF × 1.0 pocket floor (1.0 in the pocket, 1.8 standing out) |
| 16.0 | screw tip |

- Length: tip **1.4 mm = 3.5 threads past the nyloc** (1.2 mm = 3.0 threads with a 3.0-tall nut); the nylon
  ring needs ≥ 2. M2×14 would end 0.6 mm *inside* the nut (fails); M2×18 would stick out 3.4 mm. **M2×16.**
- Measured clearances: shank to palm-lug holes 0.200, shank to tongue 0.200, head to counterbore wall 0.200,
  nut flats to pocket 0.200, Base Bone to palm bone 0.200 mm.
- Sweep −15…+15° in 5° steps about `mod_j0.MC_PALM` (coincides with mates.csv Revolutes 19–22: 0.000 mm,
  0.000°): 0 mm³ overlap between the hardware and the finger chain, shank-to-tongue gap 0.200 mm at every angle.

## V5 fastener sites

**Placed (3):** `V5_BRK_I1..I3`, M2×5 + M2 hex, index palm bone, world x −91.8 / −114.1 / −133.2. The bone
still has the V5 Ø2.5 bores, Ø4.3 counterbores and closed M2 nut pockets. Snap 0.03–0.07 mm onto the bores,
seat 0.25 mm lower than V5 (counterbore floor). Hole, seat, pocket and tip checks pass; tip 0.70 mm
(1.7 threads) past the nut. Two warnings:
- **They join nothing after `mod_fixes`.** The cover3 bracket straps sat inside the bone volume here (the
  V5 simulacra interference); `fixes` trims them back to the bone surface, which removes the 0.75 mm strap
  flange under each head, so the screws clamp only the palm bone. Without `fixes` the strap is under the
  head but overlaps the bone. Suggested fix: pocket the index bone for the strap (strap + 0.2 mm) instead of
  trimming the strap. Otherwise drop these three screws.
- Head stands **0.25 mm proud** of the palm face (the V5 counterbore is 1.75 deep, the head is 2.0). Deepening
  it would leave only 0.5 mm of strap under the head, so leave it or use a low-head M2.

**Not placed (35, "open items" in the report with coordinates):**

| group | V5 count | why not | owner to request |
|---|---|---|---|
| pinky brackets BRK_P1–P4 (M2×5 + nut) | 4 | bone side has Ø2.5 + nut pocket, **cover2 strap has no hole** | shells/cover2 owner: cut Ø2.4 + Ø4.2 counterbore (strap 2.5 thick → counterbore ≤ 1.5) |
| thumb-hinge bracket BRK_T1 (M2×5) | 1 | no hole in the index bone at x −151.6 | thumb |
| driver mounts DRV (7 × M2×8, 1 × M2×5) | 8 | cover2/cover_back solid; cover3 keeps 3 Ø2.5/Ø4.3 holes but the V5 nut sat on the board | electronics |
| battery lid BAT1–8 (M2×5 + nut) | 8 | Shell1 solid on the axes; case redesigned | electronics |
| fingertip anchors TIP1–5 (M1.6) | 5 | distal phalanges have no anchor bore / nut slot | actuation |
| thumb gimbal THB1–3 (M1.6) | 3 | old hinges replaced by the thumb redesign | thumb |
| cover_back / Shell1 CBK1–6 (M1.6) | 6 | no through holes in cover_back | shells |

## BOM

Placed now (verified build; the report's `bom` is regenerated on every build and includes later requests):

| qty | item | spec to buy | where |
|---|---|---|---|
| 4 | M2×16 socket-head cap screw | ISO 4762 / DIN 912, A2-70 stainless, fully threaded, 1.5 mm hex | J0 pivots |
| 4 | M2 nylon-insert lock nut | DIN 985 A2, s = 4.0, h ≤ 3.0 | J0 pivots, in the back-lug pocket |
| 3 | M2×5 socket-head cap screw | ISO 4762 A2-70 | index bracket sites (see warnings) |
| 3 | M2 hex nut | ISO 4032 A2, s = 4.0, m = 1.6 | captive in the index palm bone |

Expected once the owners send requests (V5 counts as the guide): about +13 M2×5 and +13 M2 hex nuts
(brackets, battery lid), M2×8 for the driver boards (10 boards in V6, electronics decides the count),
and about 14 M1.6 screws + nuts (anchors, shells; thumb TBD).

Order: packs of **20 × M2×16, 20 × M2 nyloc, 50 × M2×5, 50 × M2×8, 50 × M2 hex, 20 × M2 washers ISO 7089,
20 × M1.6×3, 20 × M1.6×5, 50 × M1.6 hex (ISO 4032)**, a **1.5 mm ball-end hex key** (it fits every screw here),
a 4 mm nut spinner, and heat-set inserts only if a request uses them. Nylocs lose grip after a few re-fits:
replace them after about 5 re-assemblies.

## Print and assembly notes

- J0: drop the nyloc (flat face down, collar out) into the 4.4 AF pocket on the back of the palm bone. Push
  the M2×16 from the palm side through lug, tongue and lug, then turn it with the 1.5 mm key; the pocket
  holds the nut. **Stop as soon as the head touches.** The joint must not be clamped: the two 0.2 mm gaps
  must stay open so the finger swings freely, and the nylon ring holds the screw without preload.
  The nut and 1.4 mm of thread stand 3.4 mm out of the back lug; that space is claimed in `regions/hardware.json`.
- J0 play: the tongue turns on the thread crests in a Ø2.4 hole (0.2 mm per side, as required). Its tilt
  is limited by the 0.2 mm side gaps to roughly ±1.5°, which gives a few mm of wobble at the fingertip.
- Index bracket nuts sit in **closed** pockets inside the index palm bone (world z 0.4–2.5). Pause the print
  at the layer that closes them (about bone-local y −0.9 or −3.0, depending on print orientation) and drop in
  3 M2 nuts. This is a separate pause from the TPU pause (y 0.5–1.1).

## Region claims and conflicts

`regions/hardware.json` claims each J0 fastener envelope (counterbore to screw tip + 0.2) and a 10 mm
straight hex-key approach, both in the palm-bone local frames, and the three BRK envelopes plus key access
in `palm_index` local.
`pillars.json` draft boxes (palm_index x 22.5–28.7 / 41.7–47.9 / 61.9–68.1, y −2.5…4.3 "wall zones")
overlap the BRK_I1–I3 claims. The built pillar geometry still leaves every BRK hole, head, pocket and tip
envelope clear (validation passes on the pillar-modified bone), but the pillars' wall zones and the captive
nut pockets share material. If the BRK screws stay, the pillars should keep 1 mm away from the pockets.

## Verification

`V6_MODULES=j0,hardware` build → `scripts/verify_hardware.py` (work/hardware/final/): **PASS**.
- Library: 12 types built, all valid single solids with identity placement and the catalogued extents.
- Joints: 7 placed, 4 OK (J0), 3 WARN (BRK, above), 0 FAIL; 35 V5 open items.
- Audit (exact `common()`, 14 instances against every other instance): **max overlap 0.00000 mm³**. Contacts are
  the designed ones: heads and nuts on their seats, screw inside its nut bore (0.010 gap), shank to tongue 0.200.
- J0: clearances 0.200 mm everywhere (above). The −15…+15° sweep (7 angles × 4 fingers, whole finger chain):
  0 mm³ overlap, own hardware to finger ≥ 0.1999 mm, shank to tongue 0.1999–0.200 mm, Base Bone × palm bone
  0 mm³.
- Earlier composed builds (j0 + pillars + thumb + electronics + fixes + hardware, `work/hardware/integ*`) also
  PASS, with the same numbers except BRK "joins nothing" (effect of `fixes`).
- Request intake, tested with synthetic files (`work/hardware/requests_test/`, report `work/hardware/test_report_req.json`):
  - a request 0.2 mm off an existing bore snaps onto it and supersedes the V5 twin;
  - a request with no hole is placed red with "head not seated / no nut seat";
  - a local-frame request on `palm_middle` resolves to that instance and is rejected as a duplicate of J0;
  - missing keys and unsupported sizes (M3) are rejected with reasons;
  - a truncated, still-being-written file is retried, then reported "unreadable, skipped this build";
  - nut-face inference reproduces the J0 stack exactly on all four fingers (face 11.8 mm, flats aligned).
- Build cost: about 12–18 s of validation per build; `write_manifest`'s second `instances()` call hits a cache.

Request files at the time of writing: **none** (`regions/fasteners_*.json`). Later requests are placed and
validated automatically on the next build, and the report's `requests` section lists each file's status.

## Assumptions and open questions

- DIN 985 formally starts at M3; the M2 nyloc follows supplier data: s 4.0, h 2.8 (2.7–3.0), m ≥ 1.6.
- V5 M1.6×3 screws were pan heads (k 1.3). M1.6 requests are served with ISO 4762 heads (Ø3.0 × 1.6), so
  counterbore Ø3.4 × 1.8.
- Decision needed from the orchestrator: keep the index bracket screws (and pocket the bone instead of
  trimming the straps) or drop them.

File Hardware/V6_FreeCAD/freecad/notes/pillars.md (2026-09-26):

# Pillars: palm-bone reinforcement through the TPU palm (requirement 6) and TPU clearance fixes

Module `lib/mod_pillars.py`. Check `scripts/verify_pillars.py`, which **passes with 0 failures** on `work/pillars/test.FCStd`. Claimed regions are in `regions/pillars.json`.

Pipeline order: `j0, pillars, …`. Build: `V6_MODULES=j0,pillars`, about 90 s, 0.45 GB peak.

## 1. Problem (measured)

The TPU palm is 8 pieces that touch edge to edge and fuse into **one connected sheet** (verified):
- 4 strips (`Palm1`, `Palm2_2`, `Palm3_2`, `Palm_pinky`)
- 3 webs (`Palm2`)
- the wrist plate (`palm_bone_flex`)

The sheet is 0.6 mm thick and lies in one plane, world z −1.623 … −1.023. In bone-local coordinates that is y 0.5 … 1.1, with the palm side at −y. Its Ø2 × 3 pegs point toward the back of the hand.

In every palm bone this layer is empty from the wrist end to x = 71, where the J0 block starts. The palm half and the back half of the bone therefore joined only at the J0 block, so the full ~70 mm length acted as two thin beams. That is the break at the strip ends the user reported.

The wrist segments had the same split across their finger-side bar. There the back half-bar is about 2 mm thick.

TPU interferences in V5 + j0: the coordinator's audit list. Two causes:
- The ring and pinky wrist ends were never slotted for the plate and the ring strip.
- The webs ran through 0.07–0.17 mm skins on the +z sides of the middle and ring bones.

## 2. What the module does

All dimensions are in mm. Clearance is C = 0.2 per side.

### Palm bones (only the TPU layer, the peg holes and the pillars change)

1. **Pocket.** Each TPU instance near the bone is sectioned at 3 heights in the layer. The union of those sections is offset by C and cut through the layer (y 0.5 … 1.1). This does four things:
   - slots the ring and pinky wrist ends;
   - removes the web skins;
   - gives the insert 0.2 mm in-plane clearance to every pocket wall (the J0 block face at x ≈ 71.2, and the solid index/pinky end caps);
   - does not touch the halves' faces. The sheet is sandwiched: contact top and bottom, no overlap.
2. **Pillars.** PLA fills the layer over each footprint. The footprint is fused 0.15 mm into both halves, where the material already exists.

| bone | pillars (bone-local) | PLA cross-section in the TPU mid-plane, left of the J0 block (mm²) |
|---|---|---|
| index | rib 1 polygon x 22.4–25.4, z −4.4…4.2 (a band on the wrist side of the cover3 nut pocket I3); rib 3 polygon x 62.1–67.1, z −6.2…5.8 | 19.3, 45.7; plus the existing solid wrist end 32.1 |
| middle | stadiums at x 25.6 (5.8 × 5.4), 45.5 (5.75 × 5.4), 66.0 (6.95 × 5.4); wrist end x 1.55–4.5 × z ±4.8 (through the plate) | 25.1, 24.8, 31.3, 26.5 |
| ring | the same as middle, shifted by z +0.1 … 0.15; wrist end x 1.65–4.5 × z ±4.95 | 24.8, 24.9, 31.3, 26.5 |
| pinky | polygons at rib 1 (x 22.4–27.1), rib 2 (x 42.3–48.3) and rib 3 (x 62.2–68.3) | 26.6, 27.5, 46.3; plus the existing solid wrist end 44.9 |

The J0 block is 221–237 mm² in every bone.

**Result:** the mid-span piece of each bone (x 7…70, with the wrist end and the J0 block removed) is now **one solid**. In V5 + j0 it was 2: the split halves.

### Placement rules

Placement was done on a 0.05 mm raster (`work/pillars/scratch/raster_opt2.py`, `poly_pillars.py`). It uses the V5 bone after the pocket cut and 30 section levels 0…1.2 mm deep into each half.

- **3D wall ≥ 1.2 mm** (raster margin 1.25) from every void of either half: seat windows and troughs, peg holes, cover2/cover3 screw bores. This includes the **hardware keep-outs of the three index bracket M2×5 screws with captive nut pockets** (`regions/hardware.json`). No pillar and no TPU hole lies over a nut pocket; the minimum 3D distance is 1.26 mm.
- **TPU ligament ≥ 1.2 mm** around every hole (hole = pillar + 0.2): to windows, sheet edges and every peg.
  - The wrist-end holes stop at x ≤ 4.7. That keeps 1.2 mm to the plate/strip seam at x ≈ 5.93, so the design also works if the TPU is printed as separate pieces.
- **Pillar width.** Stadiums are at least 5.4 mm wide. Polygons are at least 2.4 mm wide (opening radius 1.2, then a 0.1 mm inset).
- **Index rib 2 has no pillar.** Its nut pocket I2 fills the rib centre, and nothing ≥ 2.4 mm wide fits with 1.2 mm walls.
- **Actuation.** The current magazine design (`regions/actuation_motors.json` of 21:28) keeps every motor envelope, with `n20.body_envelope(0.2)`, cap, 8 mm plug keep-out and shaft, **≥ 6.4 mm** from all pillars.

### Peg holes

The V5 holes were Ø2.5 but up to 0.08 mm off the peg axes. They are reamed to r = 1.21 about each peg's own axis.

### Wrist segments (Palm_bone1 frame, TPU layer at z −1.1 … −0.5)

- **Pocket.** The same C-offset pocket rule. It fixes the 0.03–0.08 mm³ plate slivers.
- **Bar pillars.** A bar pillar fills the layer in the finger-side bar between the two plate pegs:
  - `wrist_middle`: 14.1 mm²
  - `wrist_ring`: 17.0 mm²

  The pillar stops 0.2 mm inside the finger face, so the plate's exposed hinge strip keeps its full width.
- **`wrist_index` and `wrist_pinky`** get no bar pillar. Their two pegs are 3.9 mm apart. Their outer sides are already solid through the layer, since the plate spans only x 6…56.
- PLA in the layer per segment: 92.0, 103.6, 103.0 and 97.6 mm².

### TPU parts

- **Holes** are the pillar footprint plus 0.2.
- **Pegs** are shortened by 0.25, so each peg tip has ≥ 0.2 mm to the bottom of its hole.
- **Webs are unchanged.** `tpu_web` is not rebuilt; it is shared by 3 instances and no hole reaches it.
- Volumes before → after (mm³):

| part | before | after |
|---|---|---|
| index | 545.0 | 495.0 |
| middle | 545.0 | 484.7 |
| ring | 545.0 | 484.8 |
| pinky | 428.0 | 353.9 |
| wrist | 502.3 | 436.9 |

## 3. Verification (`verify_pillars.py`, assembled pose, link placements)

- **Validity.** All 14 parts pillars touches are valid single solids. Bone volumes change by +37 / +57 / −6 / +44 mm³ versus j0; the ring loses its non-physical overlapping end cap.
- **Halves joined.** The mid-span is 1 solid for all 4 bones. Every pillar footprint is 100 % backed by material just below and just above the layer, so it prints continuously.
- **TPU × PLA:** 24 pairs, **maximum overlap 0.000 mm³**, **minimum in-plane gap 0.200 mm**.

Coordinator audit list, before → after:

| pair | overlap before (mm³) | overlap after (mm³) | in-plane gap after (mm) |
|---|---|---|---|
| ring × palm_bone_flex | 44.46 | 0 | 0.200 |
| ring × Palm3_2 | 23.57 | 0 | 0.200 |
| pinky × palm_bone_flex | 15.25 | 0 | 0.200 |
| middle × Palm2 <1> | 5.22 | 0 | 0.294 |
| ring × Palm2 <2> | 2.04 | 0 | 0.284 |
| middle × Palm2_2 | 1.44 | 0 | 0.200 |
| middle × Palm1 | 0.09 | 0 | 3.5 |
| ring × Palm2_2 | 0.025 | 0 | 3.4 |
| Palm_bone1 <1>/<2>/<4>/<5> × plate | 0.03–0.08 | 0 | 0.200 |
| pinky × Palm2 <3> | near-touch | 0 | 0.273 |
| pinky × Palm3_2 | near-touch | 0 | 5.1 |

- **Pillars to TPU:** gap ≥ 0.200 mm.
- **32 pegs to their holes:** ≥ 0.204 mm, radial and at the tip.
- **TPU sheet:** still 1 connected solid, and the webs are unchanged.
- **Range of motion:** not affected. No joint geometry changed; the J0 region beyond x 71.2 is untouched.

## 4. Printing: orientation and pause (decision)

**Print the palm bones and the wrist segments back-side down (palm face up).**

The pegs then drop into their pre-printed Ø2.42 holes. That is the V5 intent: clearance holes the same depth as the pegs. The pillars are printed from the back half up through the TPU layer.

- **Pause** after the layer whose top is the **TPU palm-side face**: world z −1.023, bone y 0.5, wrist-frame z −0.5. At that point the pillars stand exactly 0.6 mm tall, flush with where the sheet's top will be.
- **Pocket floor:** world z −1.623.
- **Layer grid:** keep 0.2 mm layers across the pocket, so both heights fall on layer boundaries.

| part (as bed face) | bed plane | pocket floor at | **pause after** | notes |
|---|---|---|---|---|
| palm bone, V5 back (j0 + pillars) | bone y +7.5 (world z −8.023) | 6.40 mm | **7.00 mm** (layer 35 at 0.2) | pillars = layers 6.4–7.0 |
| palm bone + actuation magazine (its region reaches bone y 35.3) | bone y +35.3 | 34.20 mm | **34.80 mm** | re-check once actuation is final |
| wrist segment | wrist z −9.0 (world −9.523) | 7.90 mm | **8.50 mm** | use a 0.3 mm first layer so 7.9 and 8.5 fall on layer boundaries |
| all palm parts in one job (needed if the TPU palm is one piece) | world z −9.523 | 7.90 mm | **8.50 mm** | V5 palm bones then start 1.5 mm above the bed and need support |

General rule: pause height = −1.023 − z_bed (world). Pocket floor = −1.623 − z_bed.

**Pause procedure:**
1. Remove strings from the pillar tops.
2. Lay the TPU palm in, pegs down. The holes slide over the pillars with 0.2 mm clearance. Press flat; the sheet must sit flush with the pillar tops.
3. Resume within a few minutes, so the pillar tops are still warm.
4. Print the first layer after the pause about 5 °C hotter and at about 50 % speed, for PLA-on-TPU adhesion and pillar-top fusion.
5. If your TPU prints thicker than 0.60 mm, add that excess as a z-offset for the resume.

**TPU palm:**
- Print it as one flat TPU part (the 8 bodies fuse into one), sheet down, pegs up. Pegs are 2.75 mm after the trim.
- The sheet must be 0.60 mm: 3 × 0.2 mm layers.

## 5. Open items for the orchestrator and user

1. **Print orientation vs actuation.** `lib/mod_actuation.py` says the magazine is "printed on the back half after the TPU pause", which implies palm-side down. Palm-down makes the TPU pegs stand 2.75 mm up during the pause, where the nozzle hits them.
   - Either keep back-side down (my decision above), with the magazine on the bed, which actuation must check for bridging and supports;
   - or flip the pegs to the palm side. That is a TPU and peg-hole change I can make, but the 3 index +z pegs would then sit about 0.3 mm from the cover3 nut pockets. They would have to move or be dropped; the pillars already lock the strip.
2. **Window pillars (big gain).** Actuation fills the old worm seats, but leaves y 0.25…1.35 open (from my draft region). That leaves a 1.1 mm void to bridge in each TPU window.
   - If the fill reaches exactly y 0.5 and 1.1 (my final region), the whole TPU window can become a pillar: about 3 × 100 mm² per bone, with no new TPU holes and 0.2 mm to the window edges.
   - It must be added after actuation in the pipeline, or by actuation.
3. **Index rib 2 has no pillar** (cover3 nut pocket I2). The index palm half is clamped to cover3 by the three bracket screws. Its halves are joined at the wrist end, rib 1, rib 3 and the J0 block.
4. **TPU assumed one printed piece.** The holes also respect the plate/strip seam, so separate pieces work too.

## 6. Files

- `lib/mod_pillars.py`
- `scripts/verify_pillars.py`
- `regions/pillars.json`
- `notes/pillars.md`
- `work/pillars/` (`test.FCStd`, `build.log`, `verify.log`, `scratch/` rasters, plots, and the placement scripts `raster_opt2.py` and `poly_pillars.py`)

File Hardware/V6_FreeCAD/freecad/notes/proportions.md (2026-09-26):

# V6.1 proportions: human-like phalanx lengths

Owner: proportions agent. Files: `lib/mod_proportions.py`, `scripts/verify_proportions.py`, `regions/proportions.json`,
`data/v6_joints_v61.json` (frame overrides, to be merged by the orchestrator), fabrication data and test builds in
`work/proportions/`. One minimal edit in `lib/mod_hardware.py` (section 6).

## 1. What changed and why

The user decided to re-proportion the finger phalanges to their own hand. The source is the Leap Motion bones × 1.25
(`~/leap/reports/hand_size_vs_robot.json`). Palm, finger pitch and bone thickness are unchanged; the thickness is
intentional.

Joint-to-joint lengths in mm (distal = J3 axis to the fingertip), as built and measured in the assembled pose:

| Finger | Metacarpal J1→J2 | Proximal J2→J3 | Distal J3→tip | J1→tip |
|---|---|---|---|---|
| Index | 32.0 → **43.6** | 41.7 → **29.5** | 29.3 → **25.0** | 103.0 → 98.1 |
| Middle | 32.0 → **50.6** | 49.7 → **35.6** | 29.3 → **24.5** | 111.0 → 110.7 |
| Ring | 32.0 → **49.5** | 41.7 → **27.8** | 29.3 → **21.5** | 103.0 → 98.8 |
| Pinky | 25.0 → **32.9** | 31.7 → **25.0** | 29.3 → **21.0** | 86.0 → 78.9 |
| Thumb | 32.0 (unchanged) | R5→R6 41.7 → **33.0** | R6→tip 29.3 → **22.0** | R5→tip 71.0 → 55.0 |

Choices behind the table:
- **Pinky.** The Leap gives 26.3 / 19.7 / 13.9 mm, which is 32.9 / 24.6 / 17.4 after scaling. The distal is clamped to
  21.0, because the M1.6 anchor and the fingertip pad need 20–22 mm. The middle phalanx is grown slightly, from 24.6 to
  25.0, as the brief's table (~25) asks.
- **Thumb.** The brief's "R4→R6" is the `thumb_proximal` key (R5→R6, 41.7 mm now). The Leap gives 26.4 × 1.25 = 33.0
  for it, and 17.4 × 1.25 = 21.75 for the distal. I used the table's rounded 22.0. The thumb metacarpal is unchanged.
- **Minimums.** The shortest middle phalanx is 25.0 (limit 22). The shortest distal is 21.0 (limit 20–22).

## 2. Method: splicing the finished bones

`mod_proportions` runs after every module that shapes the bones:
- actuation: tendon channels, knot pockets, open-roof flexor slots and the distal M1.6 anchor
- tactile: pad recesses, folds, side curtains and dorsal spine channels
- thumb: the M2 bolts

`modify()` captures the shared bones and phalanx pads. `new_parts()` makes one variant per finger by splicing each part
in its own frame:
- **Metacarpal (lengthen):** cut at x_s, move the far part +d along x, and fill the gap with the section at x_s,
  extruded by d.
- **Proximal (shorten):** remove the slab [a, b] and move the far part back.
- **Distal (shorten):** remove slabs between the tip clamp and the J3 clevis, and move the tip portion +L toward J3.

Each bone keeps its proximal-side joint frame, and only the far joint or the tip moves:
- metacarpal J1 stays at x 7.5
- proximal J2 stays at x 7.5
- the distal J3 connector stays at x 29.3

**How the splice planes are chosen (at build time, from the received shape).** A face that does not contain the x
direction is anything other than:
- a plane whose normal is perpendicular to x
- a cylinder or extrusion along x

Any edge between two x-prismatic faces is parallel to x, so every change of section along x lies inside the x-extent of
such a face. The x-uniform ranges are the complement of those extents; `work/proportions/scan_sections.py` cross-checks
them with sections sampled every 0.25 mm. Each range is intersected with a semantic window:
- **Metacarpal:** between the knot pocket (ends at x 20.5) and the J2 clevis floor (j2 − 7.7).
- **Metacarpal pad:** before its J2-loop anchor (j2 − 12.06), so that the anchor moves with J2.
- **Proximal:** between the knot pocket and the J3 flexor slot (j3 − 7.7).
- **Distal:** between the M1.6 nut slot (ends at x 8.33) and the J3 clevis back wall (x 21.4).
- **Distal pad:** between its wrap start (8.2) and its J3-loop anchor (17.09).

A plane that no longer fits makes the build fail loudly. Every splice is also proven at build time by comparing the
section just before and just after it (`work/proportions/splice_proof.json`).

Splice locations (part-local x, mm):

| Part(s) | Uniform range used | Splice |
|---|---|---|
| metacarpal → index / middle / ring | 20.5–30.5 | insert 11.6 / 18.6 / 17.5 at x 25.5 |
| metacarpal_pinky → pinky | 20.66–23.5 | insert 7.9 at x 22.08 |
| proximal → index / ring | 20.5–40.2 | remove 24.25–36.45 (12.2) / 23.4–37.3 (13.9) |
| proximal_middle → middle | 20.5–48.2 | remove 27.3–41.4 (14.1) |
| proximal_pinky → pinky | 20.5–30.2 | remove 22.0–28.7 (6.7) |
| thumb_proximal → thumb | 20.5–40.2 | remove 26.0–34.7 (8.7) |
| distal → index / middle | 13.32–20.0 | remove 14.51–18.81 (4.3) / 14.26–19.06 (4.8) |
| distal → ring / pinky; thumb_distal → thumb | 13.32–20.0 and 10.0–13.3 | remove 13.57–19.75 (6.18) plus 10.84–12.46 / 10.59–12.71 / 11.09–12.21 |
| metacarpal pads (index / middle / ring) | 17.5–27.44 | same plane as the bone (x 25.5) |
| metacarpal_pinky pad | 17.5–20.44 | insert at x 18.97 (the bone's plane lies beyond the pad's loop anchor) |
| proximal pads | 16.7–40.0 (middle 48.0, pinky 30.0) | same slab as the bone |
| distal pads (all five) | 8.2–17.09 | own slab, centred at x 12.64 (4.3 / 4.8 / 7.8 / 8.3 / 7.3) |

**Why the ring, pinky and thumb distals need a second slab.** Only 6.68 mm of the distal is uniform between the tip clamp
and the recess end, but those three need 7.3–8.3 mm removed. The second slab lies in x 10.0–13.3. No transverse feature
crosses that range: it lies beyond the nut slot and between the ends of the blind channels at x 10.0 and 13.3. Removing
it only shortens two blind tendon passages (V5 channels at z ±0.95) and the Ø2.1 bore beyond the screw tip, from 13.3 to
11.2–12.2. The clamp itself is untouched: M1.6×3 screw seated at x 5.3, nut and side slot at x 6.5–8.3.

**Two near-x features in the sources.** Their tilt makes the sections at the two sides of a splice differ very slightly
(section symmetric difference):
- **Middle proximal:** the V5 back channel (r 1.0, inside actuation's Ø2.1 extensor channel) is tilted 0.28°. Removing
  14.1 mm leaves a 0.07 mm step on a crescent under 0.11 mm thick inside the extensor channel. Section difference
  0.127 mm², volume bookkeeping +0.85 mm³. Functionally irrelevant for the elastic cord.
- **Distal:** the M1.6 bore is tilted 0.058°. At the second slab this gives 0.002–0.004 mm².

The UnifySameDomain refinement (`removeSplitter`) fails on the received distal before any splice. It has two
sphere-capped dorsal corners at the tip. So the spliced distals keep split coplanar faces at the junction; they are valid
single solids.

## 3. Instances, poses and joint frames

**Part keys.** There are 28 new keys:
- `proportions_{metacarpal,proximal,distal}_{index,middle,ring,pinky}`
- `proportions_{proximal,distal}_thumb`
- `proportions_pad_…` for the matching phalanx pads

**`relink()`.** It points these instances at their variants:
- every finger bone instance: Metacarpal <1..3>, Metacarpal_pinky, Proximal <1>/<2>, _middlefinger, _pinky, Distal <1..4>
- the thumb's Proximal <3> and Distal <5> (this overrides mod_thumb's relink, which comes earlier)
- the 14 `tactile_pad_<finger>_{meta,prox,dist}` instances

It is unconditional. So it survives `build_v6.write_manifest()`, which reloads the modules and so loses state kept from
`modify()`.

**`placements()`.** These are pure translations, so no joint angle changes. For each finger:
- **J2 shift t2** = metacarpal rotation × (Δmeta, 0, 0). It moves the proximal, its pad and the J2 loop.
- **J3 shift t23** = t2 + proximal rotation × (Δprox, 0, 0). It moves the distal, its pad and the J3 loop.
- **Thumb:** t23 is composed on mod_thumb's re-clocked rest, and moves Distal <5>, its pad and the J3 (R6) loop by
  8.70 mm toward R5.

The tactile base poses come from `mod_tactile.instance_specs()`. So the knuckle ribbons, the wrist tails and the thumb
tail are untouched: they start at the metacarpal's knuckle exit (u 17.5), which does not move.

**Joint frames.** Nine mates have part-local connector origins that moved: Revolute 16, 13, 11 and 9 (the metacarpal J2
connector, +Δmeta), Revolute 17, 14, 12 and 10 (the proximal J3 connector, +Δprox), and Revolute 6 (the thumb proximal
R6, −8.7). They are in `data/v6_joints_v61.json`, in the same format as `data/v6_joints.json`.
- At the coordinator's request, the shared `data/v6_joints.json` was restored byte for byte, to the thumb entries only.
  The orchestrator merges the v61 file when it loads V6.1 into the master, so that geometry and frames change together.
- For Revolute 10 (pinky J3) the moved connector is entity 1, which is the pivot `rom_sweep` uses. Applied to the old
  geometry, it gave false collisions.
- `mod_proportions.write_merged()` writes a merged copy to `work/proportions/v6_joints_merged.json`.
  `work/proportions/rom_sweep_v61.py` is `scripts/rom_sweep.py` with only its overrides path configurable
  (`V6_JOINTS_JSON`), for this topic's ROM runs.

## 4. Other modules

**Tactile.**
- The 14 phalanx pads are spliced the same way as their bones. Each one is identical, to 0.00000 mm³ of symmetric
  difference, to the pad `mod_tactile` itself makes at the new length. The check is `patch_tactile()` +
  `pad_part()`, in verify [5].
- The pads stay seated: 0 overlap, 0 distance to the recess floor.
- Every spine sheet still ends at its J2/J3 loop anchor. All 23 loop-to-pad and ribbon-to-pad contacts of the moved
  and relinked parts are the tactile design's FPC butt joints, with exactly the tactile agent's volumes (≤ 0.0097 mm³).
- The fabrication data were regenerated into `work/proportions/tactile_fab/` by `work/proportions/make_fab.py`. It is the
  tactile agent's generator, unchanged except that `mod_proportions.patch_tactile()` installs the per-finger pads, the
  moved joints and the re-posed instances, and it writes into this folder. The outputs are:
  - `dxf/` (32 files)
  - `taxel_map.csv`, `readout_table.csv`, `fab_summary.json`, `taxel_map.png`

  The distal pads keep their fingertip at u 0 in the pad frame, as the generator assumes; `canon_matrix()` maps them onto
  the shortened distal.

Taxels (FlexiTac 2 mm pitch, 6 rows per digit pad):

| Board | Ray | Taxels (was) | Rows | Digit columns: distal + proximal + metacarpal | Lines available (J3 loop / J2 loop / ribbon) |
|---|---|---|---|---|---|
| 1 | thumb | 101 (148) | R1–R6 | 5 + 7 + 6 = 18 | 9 / 20 / 26 |
| 2 | index | 295 (308) | R1–R12 | 7 + 5 + 12 = 24 | 9 / 20 / 26 |
| 3 | middle | 361 (364) | R1–R12 | 7 + 8 + 15 = 30 | 9 / 24 / 30 |
| 4 | ring | 329 (340) | R1–R12 | 5 + 4 + 15 = 24 | 9 / 20 / 26 |
| 5 | pinky | 236 (261) | R1–R12 | 5 + 3 + 6 = 14 | 9 / 15 / 18 |

- The total is **1322 taxels** (was 1421).
- Every ray still fits one 16 × 32 reading board: at most 12 rows and 32 columns.
- Loops, spines, knuckle ribbons and tails keep the tactile widths, which now carry spare lines. The middle finger uses
  exactly the 30 lines of its ribbon and spine.
- Flat ray lengths: thumb 299, index 458, middle 547, ring 443, pinky 480 mm (were 315 / 463 / 547 / 447 / 487).
- No ray flat pattern overlaps itself.

**Actuation.** The moment arms are unchanged, so the excursions and spools are unchanged. Straight-finger flexor lengths
are below. The palm and base portions come from `notes/actuation.md` §7; the finger portions come from the new joint
positions (clevis floors 7.7 from the axes, knot pockets at x 19, distal clamp about 15.6 mm from the J3 floor).

| Finger | A (J1) | B (J2) | C (J3) |
|---|---|---|---|
| index | 92.8 (unchanged) | 165.8 → 177.4 | 187.3 → 182.4 |
| middle | 92.8 | 165.8 → 184.4 | 195.3 → 195.0 |
| ring | 92.8 | 165.8 → 183.3 | 187.3 → 183.1 |
| pinky | 92.8 | 158.8 → 166.7 | 170.3 → 163.2 |

- **Thumb.** T1 is unchanged. T2 (R5 + R6 flexor) is 16.0 mm shorter in the thumb: its finger portion goes from 57.3 to
  41.3 mm.
- **Elastic extensors.** The cords in the back channels change by the same amounts. They were not modelled before either.

**Thumb and hardware.**
- The R6 bolt request in `regions/fasteners_thumb.json` is a world-frame request written at the old rest pose. It is
  moved by `mod_proportions.move_world_request()`, which `mod_hardware` calls (section 6). The seat moved 8.700 mm and
  lies 0.0000 mm off the moved R6 axis.
- The R4 and R5 bolts do not move.
- `attachments_orchestrator.json`: the R2 tube rides on the yaw carrier, which is not moved.

## 5. Verification

The test build is the full chain j0, pillars, thumb, actuation, shells, fixes, tactile, proportions, hardware, run in
three stages so that each freecadcmd run stays under the 8-minute rule. The builder is
`work/proportions/build_staged.py`: stage A1 took 5:31, A2 1:20 and B 1:40. It composes modules exactly as
`build_v6.build()` does, and runs every module's relink, placements and instances hooks live, in pipeline order, on the
finished document.
- Output: `work/proportions/test.FCStd`.
- A twin without proportions, built from the same stage-A shapes, is `test_noprop.FCStd`. It is the reference for
  hardware and range of motion.
- **Electronics was left out.** Its stage alone takes about 12 minutes, its agent is still changing it, and it does not
  touch the phalanges.

Results (`scripts/verify_proportions.py`; logs and JSON in `work/proportions/verify_*`):

| Check | Result |
|---|---|
| [1] New parts | 28, all valid single solids. No instance is left on a shared phalanx part. Relinks match. |
| [2] Lengths in the assembled pose | Every target is hit with **0.0000 mm** error. The J2 and J3 connectors of the two mates coincide (0.00000 mm). Rotation change of every moved instance: 0°. J1 unchanged. The frames in `v6_joints_v61.json` match. |
| [3] Splice proof | Every kept source piece equals its translated counterpart in the variant: **0.00000 mm³** symmetric difference. Every inserted slab equals the extruded section: 0.00000 mm³. The junction sections are identical (0.00000 mm²), except for the two near-x tilts in §2 (0.127 mm² middle proximal; ≤ 0.0043 mm² distal second slab). |
| [4] Overlaps and gaps at rest | The moved and relinked instances collide with nothing. There are 23 designed contacts, all ≤ 0.0097 mm³: FPC butt joints, and pads and ribbons at their excluded flexible crossings. Joint running gaps are unchanged from the reference relative pose: fingers J1 0.300, J2 0.300, J3 0.400 mm; thumb R5 0.205, R6 0.200 mm. |
| [5] Tactile | Pads equal mod_tactile's own pads at the new length (0.00000 mm³). Pads are seated: overlap 0, distance 0. The 10 loops sit on the new joint frames: offset 0.00000 mm, angle 0°. |
| [6] Hardware | All 28 joints have the same status and the same problem texts as the no-proportions twin. The R6 bolt seat moved 8.700 mm, 0.0000 mm off the new axis. |
| [7] Combined curl (J1 = J2 = J3) | All four fingers are clear at 45°, 67.5° and 90°. At 90°/90°/90° the fingertip stops short of its palm pad by 10.9 (index), 18.4 (middle), 20.3 (ring) and 4.5 (pinky) mm. With the V5 proportions, every distal drove into the palm pad and palm bone at 90°/90°/90° (up to 1430 mm³). |

**Range of motion.** `rom_sweep_v61.py` was run on `test.FCStd` with the merged overrides:
- **Finger joints.** All finger J1–J3 (Revolute 7–18) are **clear over 0–90°**, both at the standard 9 steps and at 5°
  steps (`rom_fingers_5deg.log`).
- **Thumb.** R1, R2 (−93 to −23), R5 (Revolute 4) and R6 (Revolute 6) are clear. R4 ≥ 67.5° (metacarpal against
  cover3) and the yaw hits are identical to the twin without proportions. They are pre-existing, on the unchanged thumb
  metacarpal. In the yaw sweep with the thumb unflexed, the shorter thumb's proximal and distal intrude less at most
  angles.
- **J0 neighbour contacts.** These are the first contact above 0.5 mm³, from 1° sweeps before → after. The partner is
  still the neighbour's fingertip; the interference at first contact is smaller (for example middle −11°: 162 → 100 mm³).

| J0 | toward the thumb (+) | toward the pinky (−) |
|---|---|---|
| index | none within +15 → none | −11 → −11 (now the index distal touches the middle proximal first) |
| middle | +11 → +11 | −11 → −11 |
| ring | +11 → **+12** | −11 → −11 |
| pinky | +12 → +12 | none within −15 → none |

## 6. Edits outside this topic (and restorations)

- **`lib/mod_hardware.py`**, a minimal edit commented `# V6.1 proportions:`. It adds `_proportions_move()` and one call in
  `request_joints()` for world-frame requests. When `proportions` is in the build, a request seated on a bone that this
  module moved is moved with it. Today that is only the thumb R6 bolt. Without `proportions` it is the identity.

  It is needed because hardware creates its instances after this module's `placements()` run, and it snaps each request
  to the hole near the requested point. A pre-moved world request in another file would have left the thumb's own R6
  entry as a failing phantom bolt.
- **`regions/hardware_report.json` was overwritten by mistake** by my first test build: mod_hardware writes it on every
  build unless `V6_HW_REPORT` is set. I regenerated it with `mod_hardware.plan()` on `work/integrate_v6b/built.FCStd` —
  the build that had written the previous version — and marked the stage accordingly. Another agent's build has since
  rewritten it. My builds now write to `work/proportions/`.
- **`data/v6_joints.json`.** My frames were first merged here as the brief said. At the coordinator's request they were
  moved to `data/v6_joints_v61.json`, and the file was restored byte-identical to its previous content. It has since been
  updated by the thumb agent (Revolute 2 hi −23).

## 7. Assumptions and open questions

1. **`build_v6.load_manifest()` (the GUI path) applies relink and placements before the instance specs.** For the
   instances that modules create — here the 14 tactile pads and 9 tactile loops — tactile's specs then overwrite this
   module's relinks and placements. In the GUI those pads would snap back to the shared pads at the old positions.
   - `build()` (headless) is correct, because hooks run per module in order.
   - Fix (orchestrator's file): in `load_manifest`, apply `man['relink']` and `man['placements']` after the
     `for spec in man['instances']` loop.
   - Also, `write_manifest()` reloads the modules, so `mod_thumb.relink()` (state from `modify()`) comes out empty in
     the manifest (`"relink": {}` in `build/manifest.json`). This module's relink is unconditional for that reason.
2. **Pre-existing hardware failures.** The thumb R5 and R6 bolts fail hardware validation in the reference build too, with
   and without this module: "nut not seated: no material under the nut bearing face" and "the screw passes through
   Proximal Phalanx Bone_V02 <3> only". This is for the thumb and hardware owners. The R6 bolt keeps its exact relative
   position.
3. **Stale tactile region boxes.** The world boxes of the tactile loops in `regions/tactile.json` are at the old joint
   positions; `regions/proportions.json` has the new ones. The remaining box-level overlaps are with the same objects
   (tactile loops, thumb chain) and one AABB corner of the pinky knuckle ribbon's static segment; there is no solid
   contact (verify [4]).
4. **Opposition changes.** Thumb-to-finger opposition changes, because the thumb is 16 mm shorter and the finger J2
   joints are 8–19 mm further out. The thumb agent's opposition fit (index pad at R3 45 / R4 −45 / R6 −45) should be
   re-run with V6.1.
5. **Palm contact at full curl.** With human-like proportions the fingertips no longer reach the palm at J1 = J2 = J3 =
   90° (4.5–20 mm short). This is fine for grasping, and it removes the V5 self-collision. A power grasp that presses
   the fingertips into the palm would need J1 beyond 90°.
6. **Tactile tables.** `mod_tactile`'s own tables still describe the shared pads, and the variants exist only in this
   module. If tactile later changes a pad or recess, this module re-splices whatever it receives. The build fails loudly
   if a splice window no longer holds a uniform range. The fab data must then be regenerated by running
   `work/proportions/make_fab.py`.

## 8. Print and assembly notes

**Printing.**
- Print the new bones like the V5 ones, with the palm face up where the other owners allow it. The recess floors then
  print as top surfaces.
- They are 28 distinct parts now. Every phalanx is finger-specific, and so is every phalanx pad.
- Nothing about the joints changes: the same clevises and tongues, the integral pins at J1–J3, and the thumb M2 bolts
  (R6 is still M2×16 with a nyloc).

**Tendons and elastics.**
- Cut tendons B and C to the new lengths in §4, plus your knot allowance.
- The distal clamp is unchanged: an M1.6×3 screw with an M1.6 nut in the side slot.
- In the ring, pinky and thumb distals the blind tendon-tail passage beside the screw is 1.1–2.1 mm shorter. Trim the
  tail after clamping.
- The elastic extensor cords change by the same amounts as tendon B (metacarpal) and C.

**Tactile.**
- The FPC rays must be re-ordered from `work/proportions/tactile_fab/dxf/`: all phalanx pads changed, and so did the ray
  flat patterns. The loops, knuckle ribbons and tails are unchanged.
- The host map for the boards is `work/proportions/tactile_fab/taxel_map.csv`.
- FlexiTac-derived data remain CC BY-NC 4.0; see `notes/tactile.md`.

## 9. Files

**Deliverables:**
- `lib/mod_proportions.py`: the module. `modify` / `new_parts` / `relink` / `placements`, plus these helpers:
  - `write_joint_frames`, `write_merged`
  - `patch_tactile`
  - `move_world_request`
- `scripts/verify_proportions.py`: sections 1–7, selected with `V6_SECT`.
- `notes/proportions.md` (this file).
- `regions/proportions.json`: 5 world boxes of the re-posed segments and 28 local boxes of the new parts.
- `data/v6_joints_v61.json`: 9 frame overrides, for the orchestrator to merge into `data/v6_joints.json`.
- `work/proportions/tactile_fab/`: `dxf/`, `taxel_map.csv`, `readout_table.csv`, `fab_summary.json`,
  `taxel_map.png`.
- `lib/mod_hardware.py`: the `# V6.1 proportions:` hook (section 6).

**Tools in `work/proportions/`:**
- `build_staged.py`: staged builder, same composition and hook order as `build_v6.build()`.
- `scan_sections.py`, `inspect_faces.py`: the uniform-range analysis.
- `unit_splice.py`: module run on BREPs.
- `make_fab.py`: the tactile generator, adapted.
- `publish_joints.py`
- `make_regions.py`
- `hw_report.py`: `mod_hardware.plan()` into this folder.
- `rom_sweep_v61.py`: `rom_sweep.py` with a configurable overrides path.

**Test builds and results in `work/proportions/`:**
- `test.FCStd`: the final build. `test_noprop.FCStd`: the twin without proportions.
- `stageA1/`, `stageA2/`: stage BREPs, for a quick rebuild of stage B.
- `splice_proof.json`
- `verify_*.json` / `.log`, `rom_*.csv` / `.log`, `hardware_report_{test,noprop}.json`.

**Rebuild:**

```
P_STAGE=B P_IN=work/proportions/base.FCStd P_DIR=work/proportions/stageA2 P_OUT=work/proportions/test.FCStd \
  freecadcmd work/proportions/build_staged.py
```

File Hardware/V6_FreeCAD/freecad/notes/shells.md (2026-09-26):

# V6 shells: Shell2 solid, Shell1–Shell2 spherical joint, shell interference fixes

Owner: the shells agent.

| File | Role |
|---|---|
| `lib/mod_shells.py` | The module |
| `scripts/verify_shells.py` | 48 checks |
| `regions/shells.json` | Claimed space |
| `regions/fasteners_shells.json` | 6 screw requests |
| `work/shells/` | Tests and logs; `bake/` holds baked inputs from other parts; `cache/` holds the Shell2 rebuild |

**Frame D** is Shell1's local frame; world = Shell1 link placement × D.
- D +y points toward the fingertips (world ≈ +X).
- D +x points toward the thumb side (world ≈ +Y).
- D +z points out of the back of the hand (world −Z).

θ is the angle about the D y-axis, measured from +z toward +x.

## 1. What the "palm shells" are and how they move (interpretation)

### Measured

**Shell1's skins are exact surfaces of revolution about the D y-axis.** Circle fits at 13 stations give 0.00 mm error. Each profile is a circular arc:

| Skin | Arc radius | Arc centre (y, r) | Radius at y = −60 |
|---|---|---|---|
| Outer | R 176.04 | (−61.40, −109.56) | 66.50 |
| Inner | R 184.39 | (−60.00, −121.92) | 62.50 |

In the hand, the D y-axis runs along the middle of the palm in its back plane, through about (X −120, Y −31, Z −3.4). That is between the middle and ring palm bones, at TPU-web level. It is the line the palm cups about.

**Shell2 shares the axis.** Its underside is a surface of revolution about the same axis, 1.3–1.6 mm inside Shell1's skin in the shared native frame. It spans θ −42.7…+57.3°, while Shell1 spans −46.6…+44.4°. At the V5 pose, its top is flush with the dorsal end of cover3's thumb wall.

**Attachments (V5 fasteners):**
- cover2 is screwed to the pinky palm bone, and cover3 to the index palm bone.
- Shell1 is screwed to cover_back with M1.6 screws. This model keeps 2 bosses with nut slots.
- The battery cover is screwed to Shell1.
- Shell2 has no fastener.
- Shell1 only rests on cover2 (2.2 mm interference) and cover3 (touching). Nothing ties Shell1 or cover_back to the palm.

**How the covers move.** Rolling cover3 about the axis by +φ (cupping on the thumb side) moves it away from Shell1 and cover_back, with no collision to +20°. Rolling it by −φ collides at once, so the CAD pose is the flat-palm limit.

**The palm's own cupping stop.** Bone-to-bone contact about the TPU webs comes at 6.5° (index/middle), 14° (middle/ring) and more than 40° (ring/pinky).

### Interpretation

**The palm shells are Shell1 (the dorsal bowl) and Shell2 (the outer logo cap).** When the palm cups, the thumb side (index bone, cover3, thumb) rolls about the palm axis relative to the pinky side (pinky bone, cover2). V6 gives each shell to one side:
- **Shell1 and cover_back ride on the pinky side.** Shell1 is rebated over cover2's wall end and fixed with 2× M2. cover_back keeps its M1.6 screws to Shell1.
- **Shell2 is driven by the thumb side.** A lip on Shell2 straddles cover3's dorsal wall end with 0.2 mm clearance.

On cupping, Shell2 rolls over Shell1 about the palm axis and keeps the Shell1/cover3 seam covered; that seam opens by up to about 17 mm at +15°. Palm twist adds tilt about the other two axes, which is the "spherical" freedom.

The joint lets both happen. It keeps the shells engaged with hard stops, and holds them lightly together with rubber (O-rings).

### Alternatives rejected

| Alternative | Why rejected |
|---|---|
| Free-floating cosmetic cap (elastic only, no link to cover3) | On cupping, cover3 pulls away from Shell2's edge. That opens a slit of up to about 17 mm into the hand: the "disengage" case |
| Elastic bias of Shell2 toward cover3 | Pre-cups the very soft TPU palm (about 0.004 N·m/deg) at rest |
| Shell2 screwed rigidly to cover3 | Needs holes in cover3 (thumb and fixes own it). The lip gives the same roll coupling without touching cover3 |
| Mirror arrangement (Shell1 thumb side, Shell2 pinky side) | Shell2 does not reach cover2, and its seam with cover3 would open on cupping |
| Nested full lemons (toroidal surfaces only) | Roll only, with no tilt for palm twist |
| Keepers or elastic anchors inside the bowl | Collide with the electronics claims (battery case in the bowl crown, Mega at the wrist). Everything here is outside Shell1 |
| O-ring riding only on the cap (earlier draft) | Exerts no net force on the cap |
| Tension bands to anchors inside Shell1 | Need anchors more than 15 mm deep. At a 17 mm roll the length changes 2–3×, so centring torque is high |

## 2. Shell2 as a valid solid

**Source.** `SRC_Shell2` is one mesh face: 8,626 vertices and 17,248 triangles. It is closed and 2-manifold with consistent winding (V − E + F = 2), but globally inverted, so its volume reads −34,681.8.

**Reversing and sewing works but can't be trusted.** It gives a valid 17,248-face solid, and booleans with primitives work. But `common` with Shell1 silently returned 0 mm³ against a true overlap of about 14,000 mm³, and distance queries took 13–17 s.

So `rebuild_shell2()` builds a clean B-rep in the native frame:
- **Outer skin, including the chamfered long edges.** The mesh's outermost radius along radial rays on a 1.25° × 2.5 mm (θ, y) grid. In the logo area it uses a degree-8 Chebyshev fit of the surrounding skin (709 points, 0.150 mm max, 0.033 mm rms). Where rays miss the cap, a harmonic fill carries the skin on smoothly.
- **Underside.** A Chebyshev fit; it is a surface of revolution to under 0.001 mm.
- **Solid.** y-sections lofted between the two, intersected with a radial prism through the underside rim loop (Douglas–Peucker 0.05).
- **Logo.** The OSHW gear-with-keyhole recess, 1.1–1.9 mm deep, cut from its own floor fit with radial walls through the mesh's logo rim loop.

**Result:** a valid single solid of 34,443.6 mm³ (−0.69%) with 212 faces. Against 80 random mesh vertices, the distance is median 0.021 mm, p90 0.25, p95 0.28, max 0.65, with 84% within 0.2 mm. The worst points are rim and logo-corner vertices, which the tessellation over-samples; the skins themselves are within 0.15 mm.

It is cached in `work/shells/cache/`, keyed by the mesh and the rebuild version. The first build takes about 25 s and about 0.8 GB of RAM; later builds load the BREP.

**Placement: the "correct relationship".** It is the V5 SolidWorks one: Shell1's orientation, shifted 5.1187 mm along D +z (world −Z). The Onshape instance is about 0.5° and 4.5 mm off. At the V5 pose the top is flush with cover3's wall end, and the underside is 2.3–3.7 mm clear of Shell1. The existing `Shell2 <1>` link is kept, and the pose correction is baked into the part's geometry.

## 3. The joint (final parameters are constants at the top of `mod_shells.py`)

**Centre C = D (0, −60, 0):** on the palm axis, at Shell1's equator.

**Bearing:**
- **Shell1:** a raised spherical land, R 70.0 about C, spanning θ −36…+38° and y −68…−52, 3.5 mm high.
- **Shell2:** a concave seat, R 70.2, across its full width over y −70…−50.
- Running clearance is 0.2 mm.

**Design range:**
- Roll −1…+15° about the axis (+ = cupping).
- Tilt ±1° about the D x- and z-axes through C.

**Retention and travel limits:**
- Two Ø5 studs on Shell1 at (y −95, θ 5°) and (y −20, θ 5°) pass through arc slots in Shell2. The slots run θ −10…+6° in Shell2, because the fixed stud travels −φ in Shell2's frame. They are 8.0 mm wide: stud 2.5 + 0.2 clearance + 1.3 tilt, per side.
- The slot ends are the hard roll stops, at −2.22° and +16.22°.
- The slot sides are the tilt stops.
- The Ø13 slider washer can't pass the 8 mm slot, so the cap can't lift off: at least 1.12 mm of overlap everywhere in the full sweep.

**Elastic.** On each stud, stacked on top of Shell2:
1. slider washer, Ø13 × 1.5 (PTFE sheet preferred; PLA works);
2. silicone O-ring 5 × 2.5 (ID 5, OD 10, 40–50 Shore A);
3. printed cap washer, Ø12 × 1.2;
4. M2×8 SHCS into a Ø1.7 × 7 pilot in the stud.

The stud length sets about 10% squeeze on the O-ring at the highest seat point. The squeezed O-rings hold Shell2 down on the land and take up rattle; the slider washers slide over Shell2 as it rolls.

Force estimate, from published O-ring compression curves scaled to soft silicone: about 1–4 N per ring at 5–10% squeeze. Friction is then about 0.01–0.05 N·m with PTFE sliders, or up to about 0.1 N·m with PLA. That compares with roughly 0.3–1 N·m of palm-cupping moment under a grasp.

- Stiffer: add a 0.2 mm shim under the cap washer (about 18%).
- Softer: use 40A silicone or file 0.2 mm off the stud top.
- **Don't use 70A NBR**, which is about 3× stiffer.

Roll is driven by cover3 through the lip, so the O-rings add no spring bias.

**Thumb coupling.** A 1.6 mm U-lip on Shell2 straddles cover3's dorsal wall end over D y −72…−30. It clears both wall faces (NT·p 53.97 / 58.47) and the wall-end top (skin + 7.6–8.6 mm) by 0.25 mm. Elsewhere, Shell2's thumb end stops 0.25 mm short of cover3's wall and block faces. The lip ends at y −72, clear of cover3's R6 fillet corner.

**Pinky side.**
- The Shell1 rim is rebated over cover2's dorsal wall end, 0.2 mm all round. The rebate is an analytic slab: NP·p 51.0…55.77, D z above 42.47, y up to −107.5, each grown by 0.2.
- 2× M2×8 go through the rim (Ø2.4 hole, Ø4.4 counterbore, 2.2 mm flange under the head) into Ø1.7 × 8 pilots in cover2's wall end, at cover2 local x −62 and −22.

**Thumb side (clearance for −1° roll and ±1° tilt).**
- Shell1's thumb edge and cover_back's thumb end are cut back 2.8 mm from cover3's wall face (NT·p 53.97) and block face (46.47).
- The split between the two faces is at D y −77, which is 3 mm past cover3's R6 notch corner (−80.3) to allow for tilt.
- This fixes the cover_back × cover3 overlap (0.44 mm³ → 2.8 mm gap).

**cover_back.** Adds 2× M1.6 holes (Ø2.0, with a Ø3.4 × 1.2 head seat) at Shell1's existing wrist bosses.

**New parts** (instanced in `Hand/Shells` with Shell1's placement): `shells_slider_1/2`, `shells_oring_1/2` and `shells_capwasher_1/2`. The O-rings are drawn 0.05 mm short of both washers, because a torus tangent to a plane upsets OCC booleans and triggered an audit false positive.

## 4. Print and assembly

1. **Print the parts.**
   - Shell1 dome-up, with the studs pointing up (no support on the studs).
   - Shell2 top-up (the lip and logo need no support).
   - Two slider washers (ideally cut from 1.5 mm PTFE) and two cap washers.
   - Pre-thread every Ø1.7 pilot with an M2 screw.
2. **Fit Shell1.** Lower it onto cover2's wall end (the rebate locates it) and against cover_back. Fit 2× M2×8 through the pinky rim into cover2, and 2× M1.6×12 plus hex nuts from cover_back into Shell1's wrist bosses.
3. **Fit Shell2.** With the palm flat, lower it along D −z (straight onto the back of the hand). The lip slides down over cover3's wall end, and the studs enter the slots.
4. **Fit the stacks.** On each stud: slider washer, O-ring, cap washer, M2×8. Tighten only until the cap washer seats on the stud top; the stud length sets the squeeze.
5. **Check by hand.** Cup the palm. Shell2 should roll with cover3 smoothly to about +15° and stop at about +16°. Flatten it: it should stop just past flat. Try twisting: there should be about ±1° of free play.
6. **Service.** Two screws release the stacks, and Shell2 lifts off straight up.

## 5. Coordination

**Electronics** (`regions/electronics.json`, draft):
- My parts put nothing inside the bowl. The land, studs, slots and stacks are all outside Shell1, and the rebate and screws are at the pinky rim. The battery-case and Mega claims are respected.
- Your wrist-end claim mentions "power switch, charge port, USB grommet through cover_back / Shell1". Those openings are in my parts, so send positions and I'll cut them.
- **Keep wires, clips and boards off the thumb-side seam.** That is the Shell1 thumb edge ↔ cover3 wall, and the cover_back thumb end ↔ cover3 block. It opens and closes by up to about 17 mm as the palm cups.

**Tactile** (`regions/tactile.json`, read 00:10): its FFC runs are on the palm side, the finger backs, the knuckles and the wrist exit (palm side). The readout pod is off-hand. Nothing enters the shells or crosses the thumb seam; there is no conflict.

**Thumb and fixes (cover3):** keep cover3's dorsal wall end at D y −72…−30 as it is: a 4.5 mm plate with faces NT·p 53.97 / 58.47 and its top at the current height. Shell2's lip straddles it. Verified against the thumb-module cover3 (51,152 mm³) and the fixes-module cover2.

**Hardware:** `regions/fasteners_shells.json` requests:
- 2× M2×8 SHCS, stud caps, thread-forming;
- 2× M2×8 SHCS, Shell1 to cover2, thread-forming;
- 2× M1.6×12 SHCS + M1.6 hex, cover_back to Shell1.

All seat points are the underside of the head.

**Build input:** the 22:06 master `DexiGrab_V6.FCStd` failed in `partkeys.resolve` with StopIteration (no wrist link points at an `SRC_Palm_bone*` object). Tests used the last good master copy, `work/thumb/base.FCStd`, copied to `work/shells/base.FCStd`.

## 6. Verification (`scripts/verify_shells.py`)

Logs are in `work/shells/`:
- **`verify_final.log`:** `V6_MODULES=j0,shells`, default 12-pose sweep: 48 checks, 0 FAIL, 337 s, 1.06 GB max RSS.
- **`verify_int.log`:** `j0,thumb,shells,fixes`, with the real thumb-module cover3 and the fixes-module cover2: 48 checks, 0 FAIL.
- **`verify_full_a.log` / `verify_full_b.log`:** the full sweep, rolls −1/0/5/10/15° × tilts 0 and all four ±1° corners (25 poses), run as two sweep-only passes: 0 FAIL.
- **Global audit on the integrated build** (`scripts/audit_clearance.py`, `work/shells/audit_int.csv`): no interference involving my parts. Remaining rows are intended contacts (Shell1 × cover_back, cap washer on stud), the 0.05 mm modelled O-ring float, and the 0.200 mm running clearances.

| Check | Result |
|---|---|
| Valid single solids | Shell1 49,880.8 mm³ (was 48,772), Shell2 32,445.1, cover_back 14,781.3 (was 15,337), cover2 21,981.2 (21,898.3 after fixes), 6 stack parts |
| Shell2 source | mesh: 1 face, 0 solids, −34,681.8 mm³. Rebuild: valid, −0.69% volume |
| Shell1 × Shell2 | 0.200 mm gap, 0 overlap |
| Shell1 × cover2 | **0.200 mm gap, 0 overlap** (was 699.6 mm³) |
| cover_back × cover3 | **2.800 mm gap, 0 overlap** (was 0.44 mm³) |
| Shell2 × cover3 (lip) | 0.250 mm |
| Shell1 × cover3 | 2.800 mm |
| Shell2 × cover_back / cover2 | 3.38 / 6.44 mm |
| Sweep, 11 pairs | Shell2 × Shell1, cover2, cover_back, sliders; cover3 × Shell1, cover_back; thumb hub and yoke × Shell1, cover_back. **0 overlap** at every pose in the full 25-pose sweep |
| Shell1 × Shell2 closest approach | ≥ 0.159 mm at the (+1,+1)/(−1,−1) tilt corners at roll −1°/+15°; 0.036 mm at the mixed (+1,−1)/(−1,+1) corners. No contact inside the range |
| Retention | slider washer overlaps the slot sides by ≥ 1.34 mm (≥ 1.12 mm in the full sweep) |
| Bearing | seat stays over the land on ≥ 63° of arc |
| Travel stops | design limits −1° / +15° are free; hard stops (stud at slot end) at −2.22° / +16.22° |

Runtime notes:
- The default run (`SHELLS_QUICK=1`) fits one 10-minute foreground call.
- For the full 25-pose sweep use `SHELLS_QUICK=0`, or split it: `SHELLS_SWEEP_ONLY=1 SHELLS_ROLLS=-1,0,5 SHELLS_TILTS=5`, then `SHELLS_ROLLS=10,15`.

## 7. Open questions for the user

1. **Design range.** Roll −1…+15° with ±1° tilt was chosen from the bone-contact limits and a realistic grasp. Is 15° of cupping enough? More is possible: about +20° is collision-free for cover3, but the slots and the land would get longer.
2. **O-ring squeeze.** It is an estimate. Tune it by shims on the first print (see §3).
3. **Shell2 top fidelity.** The tapered long edges and logo corners are reproduced to about 0.3–0.6 mm at the corner vertices. If exact 3MF fidelity matters for printing the logo, confirm that the recess depth of about 1.5 mm is fine.
4. **Arm mount.** The hand's root is undefined in this CAD. With this split, cover_back and Shell1 belong to the pinky side, so an arm mount on cover_back carries the hand through the pinky group and the TPU palm. If the arm should hold the thumb side, cover_back could be re-assigned to cover3. That needs a screw joint on cover3, which is the thumb module's part.

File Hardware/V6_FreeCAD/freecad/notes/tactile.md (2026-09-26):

# V6 tactile skin: FlexiTac pads on every grasp surface

Owner: tactile agent. Files: `lib/mod_tactile.py`, `scripts/verify_tactile.py`, `regions/tactile.json`,
`regions/attachments_tactile.json`, `regions/fasteners_tactile.json`, fabrication data in `work/tactile/`
(`dxf/`, `taxel_map.csv`, `readout_table.csv`, `taxel_map.png`, `fab_summary.json`, generator `make_fab.py`).
Test build: `j0,pillars,thumb,actuation | shells,electronics | fixes,tactile,hardware` in three stages
(`work/tactile/staged_build.py`, same composition and hook order as `build_v6.py`, including the thumb's
`placements()` re-clock) → `work/tactile/test.FCStd`. The electronics stage alone takes about 12 minutes now.

## 1. FlexiTac in one paragraph (and the licence)

FlexiTac (Huang & Li, Columbia, 2026; https://flexitac.github.io) is a piezoresistive matrix: two 0.2 mm FPCs
(top = row electrodes, bottom = column electrodes) with Velostat/Linqstat between them, each FPC laminated and the
edges sealed with polyimide tape, about 0.6–0.8 mm thick, taxels at 2 mm pitch. A "Reading Board 32x16" (Arduino Nano,
one 16-channel analog mux for the rows, four shift registers for the columns, 0.5 mm FFC connectors, 16-pin rows and
32-pin columns) scans 512 taxels and streams frames `0xAA 0x55` + 512 bytes at 2 Mbaud over USB serial.

**Licence: FlexiTac is © 2026 Columbia University, CC BY-NC 4.0.** Attribution is required and commercial use is
not allowed. The FPC outlines in `work/tactile/dxf/` are adaptations of the FlexiTac sensor design and the readout
reuses the FlexiTac board and firmware unchanged, so the same terms apply to anything built from them.

## 2. Coverage plan

One pad per rigid segment, on its palm face. No pad crosses a joint; every joint is crossed by a flexible tail.

| Segment | Part key (instances) | Taxels | Pad |
|---|---|---|---|
| distal ×4 | `distal` (index, middle, ring, pinky) | 46 | D-shaped, 12.4 × 18.8 mm, follows the R 7.5 tip to 1.2 mm from the edge |
| proximal | `proximal` (index, ring) / `proximal_middle` / `proximal_pinky` | 66 / 90 / 36 | 12.4 × 23.3 / 31.3 / 13.3 mm |
| metacarpal | `metacarpal` (index, middle, ring) / `metacarpal_pinky` | 36 / 18 | 12.4 × 13.6 / 6.6 mm |
| thumb | `thumb_distal`, `thumb_proximal`, `thumb_metacarpal` | 46 + 66 + 36 | as the finger parts; proximal and metacarpal wrap to the other side |
| palm | `palm_index`, `palm_middle`, `palm_ring`, `palm_pinky` | 160, 192, 192, 161 | 12.4 × 70.1 mm on each palm bone |

**Total: 1421 taxels** (thumb 148, index 308, middle 364, ring 340, pinky 261).

Not covered, and why:
- **Base Bone 1** (between J0 and J1): its palm side sits under the palm bone's J0 lug, the metacarpal clevis floor
  sweeps its J1 head with a 0.2 mm running gap, and it carries the flexor groove. There is no flat, static face.
- **The webs between the palm bones.** The palm between the bones is the flexible TPU insert. A pad spanning a web
  would put a laminated stack across the bending TPU and tear or delaminate. So the palm gets one pad per palm bone,
  and the webs stay bare (about 2–3 mm between the pads).
- **Joints and knuckles**, by rule. The loops cross them on the back of the hand.
- **Side faces.** The strap-side face of every bone carries the FPC wrap (fold and curtain), so it is not sensitive.
  I did not add index or thumb side pads: the side faces are 15 mm tall with R6 corners and already carry the wrap on
  one side. A side pad would need its own tail around the joint, and there is no free channel for it.
- **Fingertip wrap.** The pad follows the R 7.5 fingertip in plan (D shape) but does not wrap the tip bevel. The tip is
  doubly curved: a 0.8 mm laminated stack cannot follow it without darts, and darts would cost more taxels than the
  wrap gains.

## 3. Pad, recess and wrap geometry (canonical pad frame u, v, w; w toward the palm, face at w 7.5)

- **Stack 0.8 mm (budget) in a 0.6 mm recess: pads stand 0.2 mm proud** of the PLA face, so a contact loads the pad
  before the rim. If your laminated stack comes out at 0.6 mm, the pads sit flush. The recess keeps 0.2 mm clearance
  to its walls (end walls ≥ 1.0 mm, non-strap side wall 0.8 mm).
- **Wall over internal channels:** recess floor at w 6.9 against the flexor-channel roofs at w 5.75 in all phalanges,
  so at least 1.10–1.15 mm. The metacarpal and distal recesses stop 0.3 mm short of the flat top so their corners keep
  1.06 mm to the flared flexor-channel entries (cones r 2.0 → 1.05). The actuation knot pockets (Ø3 from the palm face)
  are bridged by the pad. The thumb distal wraps to the same side as the finger distals, away from the M1.6 anchor nut
  slot.
- **The FPC wrap (both FPCs):** each phalanx pad's FPCs fold over the strap edge (R 1.0 inner radius), run down the side
  face in a 0.6 mm channel, around the dorsal R6 corner and onto the back, where a dorsal **spine** channel
  (0.6 deep, FPC width + 0.2 wide) carries the ray to the joints.
- **Palm bones:** above w 2.7 the rounded section corners are squared off to give a flat pad bed, and the open V5
  trough-3 notch (u 51.5–62.5) and the trough-1/2 slivers are filled from the TPU layer up. The palm pad's FPCs fold over
  the strap edge into a 0.6 mm **curtain channel** on the side face (w 0.1–5.9, i.e. a 0.6 mm, three-layer PLA lip
  above the TPU web slot). The curtain runs to u 62.5 and the channel continues to u 73.3 to take the digit ribbon.
- **Strap screws:** the palm pads have Ø4.6 holes at the V5 bracket screws BRK_I1–I3 (index) and BRK_P1–P3 (pinky);
  heads and key stay reachable. The cover3 and cover2 strap tops are lowered 0.57 mm over the pad recess.
  **P4 has no V6 screw** (it is listed as unplaced by hardware); the pinky ray tail crosses that strap top in a
  lowered channel.
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

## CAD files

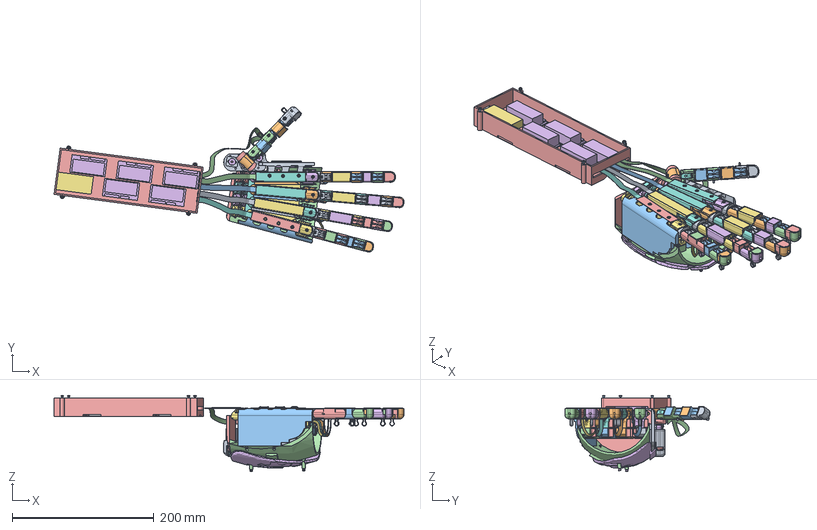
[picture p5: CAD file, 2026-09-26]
Hardware/V6_FreeCAD/freecad/DexiGrab_V6.FCStd
494.6 x 205.4 x 108.1 mm
V6 base_bone x 4
V6 proportions_metacarpal_index
V6 proportions_proximal_index
V6 proportions_distal_index
V6 proportions_proximal_ring
V6 proportions_distal_ring
V6 proportions_metacarpal_ring
V6 thumb_hinge3
V6 proportions_distal_thumb
V6 thumb_hinge2
V6 proportions_proximal_thumb
V6 thumb_metacarpal
V6 thumb_hinge1
V6 thumb_hub
V6 thumb_r2_tube
V6 proportions_metacarpal_middle
V6 proportions_proximal_middle
V6 proportions_distal_middle
V6 proportions_proximal_pinky
V6 proportions_distal_pinky
V6 proportions_metacarpal_pinky
V6 palm_index
V6 palm_pinky
V6 palm_ring
V6 cover3
V6 palm_middle
V6 cover2
V6 shell1
V6 cover_back
V6 shell2
SRC_Palm2 x 3
V6 tpu_wrist
V6 tpu_ring
V6 tpu_index
V6 tpu_middle
V6 tpu_pinky
V6 wrist_index
V6 wrist_ring
V6 wrist_pinky
V6 wrist_middle
V6 hardware_m2x16_shcs x 6
V6 hardware_m2_nyloc_nut x 9
V6 hardware_m2x5_shcs x 8
V6 hardware_m2_hex_nut x 9
V6 hardware_m2x14_shcs x 3
V6 hardware_m2x8_shcs x 5
V6 hardware_m1p6x3_shcs x 6
V6 hardware_m1p6x12_shcs x 2
V6 hardware_m1p6_hex_nut x 2
V6 hardware_m2x12_shcs x 4
V6 hardware_m2_insert x 4
V6 thumb_n20
V6 actuation_n20 x 18
V6 actuation_spool_small x 10
V6 actuation_spool_big x 4
V6 actuation_spool_double x 4
V6 actuation_tray_index
V6 actuation_tray_middle
V6 actuation_tray_ring
V6 actuation_tray_pinky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

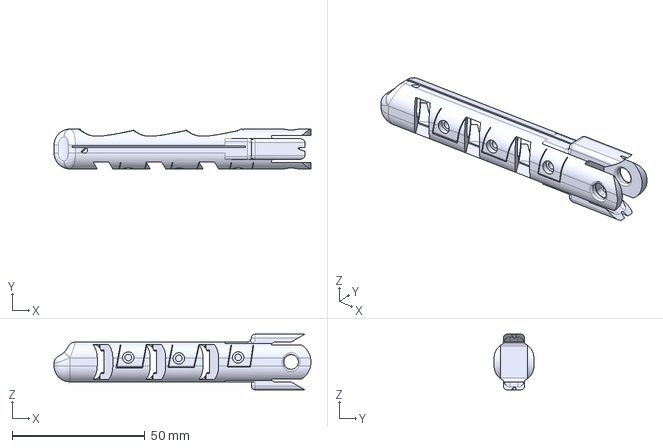
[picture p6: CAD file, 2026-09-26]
Hardware/V6_FreeCAD/v5_step/Robotic Hand_V5_simulacra - Base Bone 1.2_V02_pointerfinger_and_thumb_attachment.step
96.8 x 15.0 x 21.0 mm

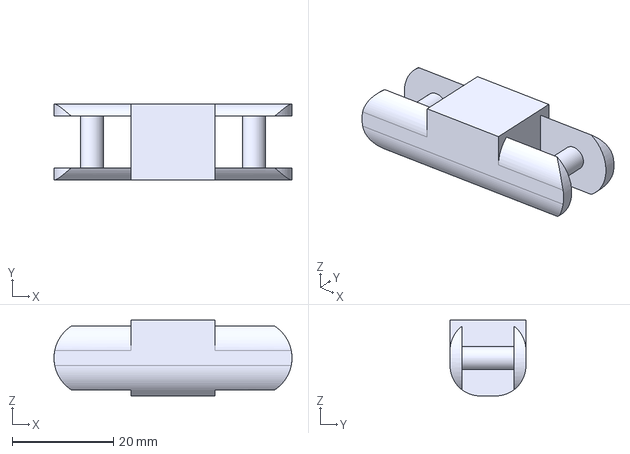
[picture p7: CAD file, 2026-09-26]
Hardware/V6_FreeCAD/v5_step/Robotic Hand_V5_simulacra - Metacarpal Bone_V02.step
47.0 x 15.0 x 15.0 mm

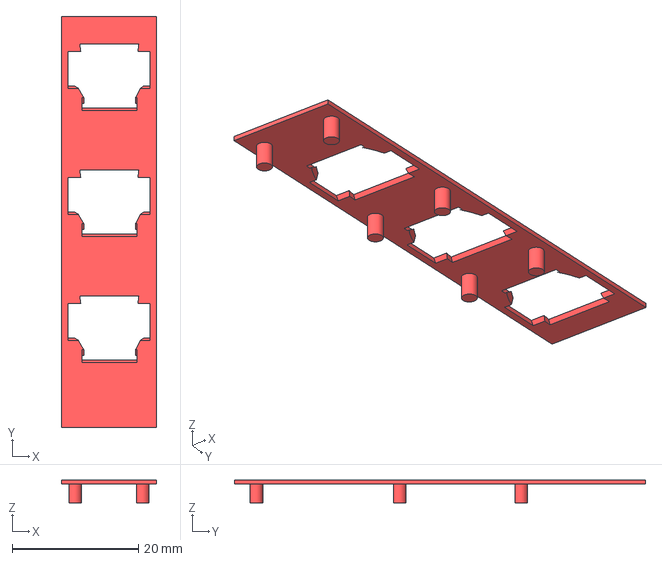
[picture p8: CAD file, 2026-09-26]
Hardware/V6_FreeCAD/v5_step/Robotic Hand_V5_simulacra - Palm_pinky.step
15.0 x 65.0 x 3.60 mm

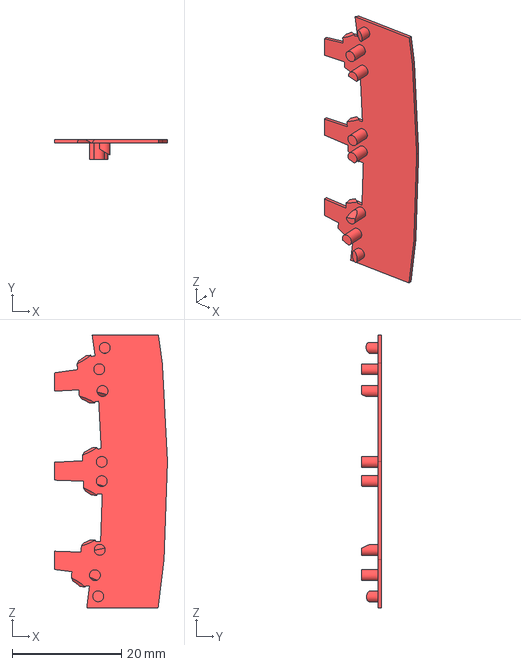
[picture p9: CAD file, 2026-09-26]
Hardware/V6_FreeCAD/v5_step/Robotic Hand_V5_simulacra - palm_bone_flex.step
20.7 x 3.60 x 50.0 mm

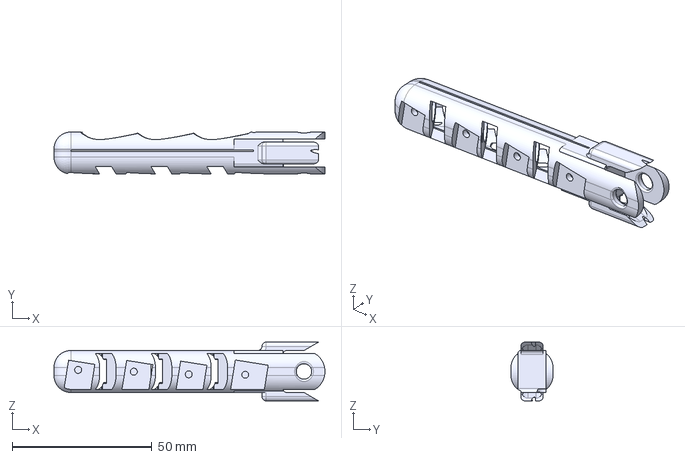
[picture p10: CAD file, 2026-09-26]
Hardware/V6_FreeCAD/v5_step/Robotic Hand_V5_simulacra - Base Bone 1.2_V02_pinky.step
96.8 x 15.0 x 21.0 mm

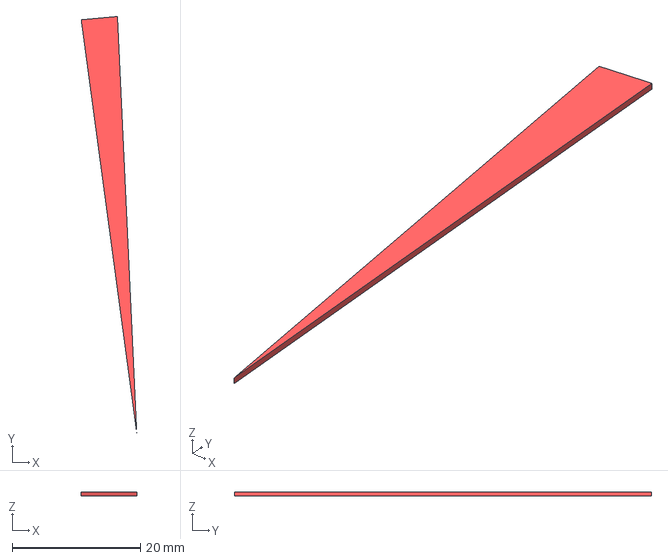
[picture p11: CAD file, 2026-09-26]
Hardware/V6_FreeCAD/v5_step/Robotic Hand_V5_simulacra - Palm2.step
8.65 x 64.9 x 0.6 mm

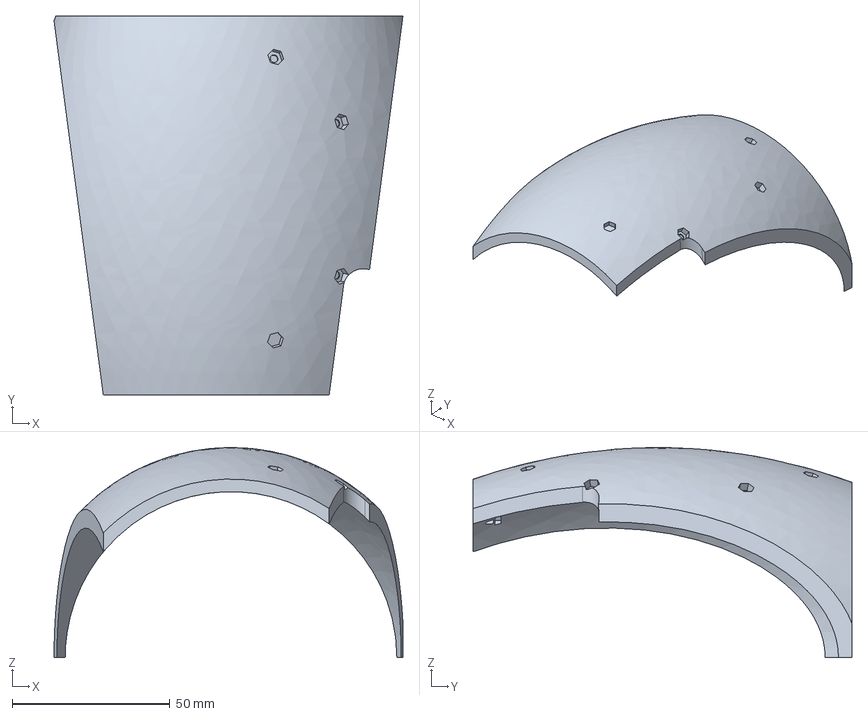
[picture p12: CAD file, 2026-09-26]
Hardware/V6_FreeCAD/v5_step/Robotic Hand_V5_simulacra - Shell1.step
110.5 x 120.0 x 66.5 mm

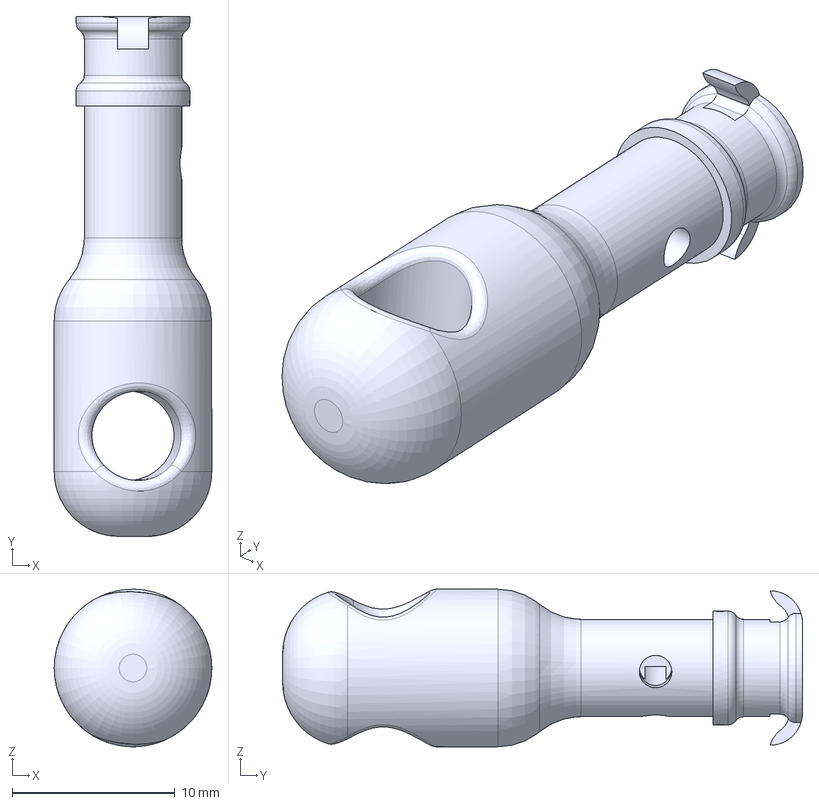
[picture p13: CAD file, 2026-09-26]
Hardware/V6_FreeCAD/v5_step/Robotic Hand_V5_simulacra - third_thumb_hinge.step
9.70 x 32.0 x 9.70 mm

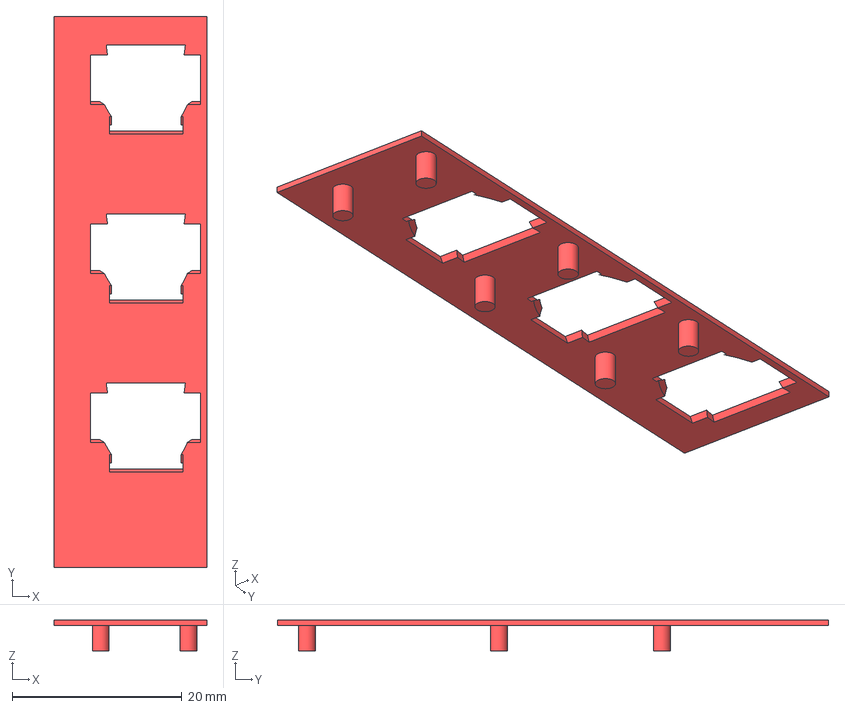
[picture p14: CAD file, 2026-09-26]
Hardware/V6_FreeCAD/v5_step/Robotic Hand_V5_simulacra - Palm1.step
18.0 x 65.0 x 3.60 mm

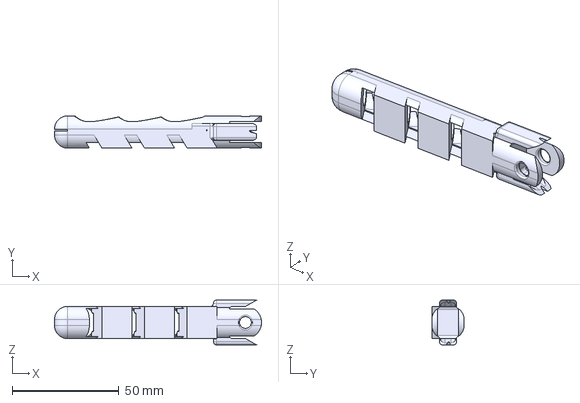
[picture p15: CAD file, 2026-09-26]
Hardware/V6_FreeCAD/v5_step/Robotic Hand_V5_simulacra - Base Bone 1.2_V02_middlefinger.step
96.8 x 15.0 x 21.0 mm

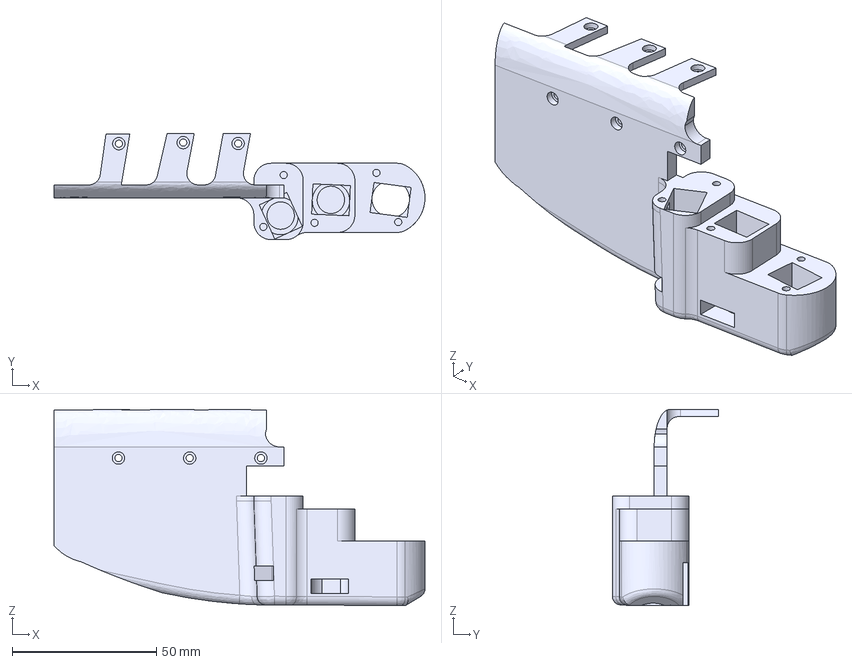
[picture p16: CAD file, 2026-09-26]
Hardware/V6_FreeCAD/v5_step/Robotic Hand_V5_simulacra - driver_side_palm_cover3.step
128.7 x 36.9 x 68.0 mm

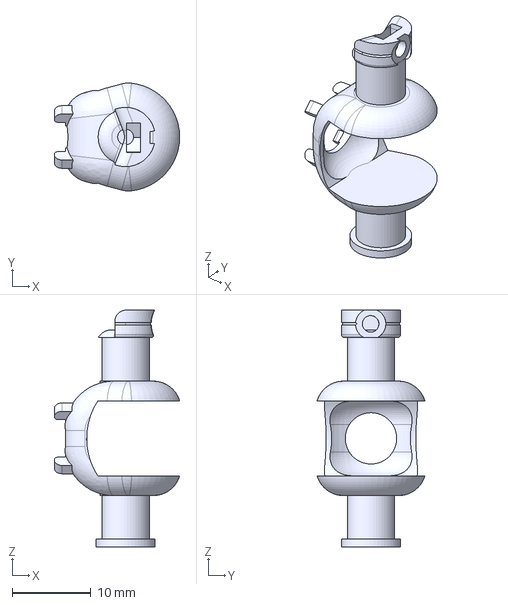
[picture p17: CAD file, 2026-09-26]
Hardware/V6_FreeCAD/v5_step/Robotic Hand_V5_simulacra - second_thumb_hinge.step
15.9 x 13.7 x 30.0 mm

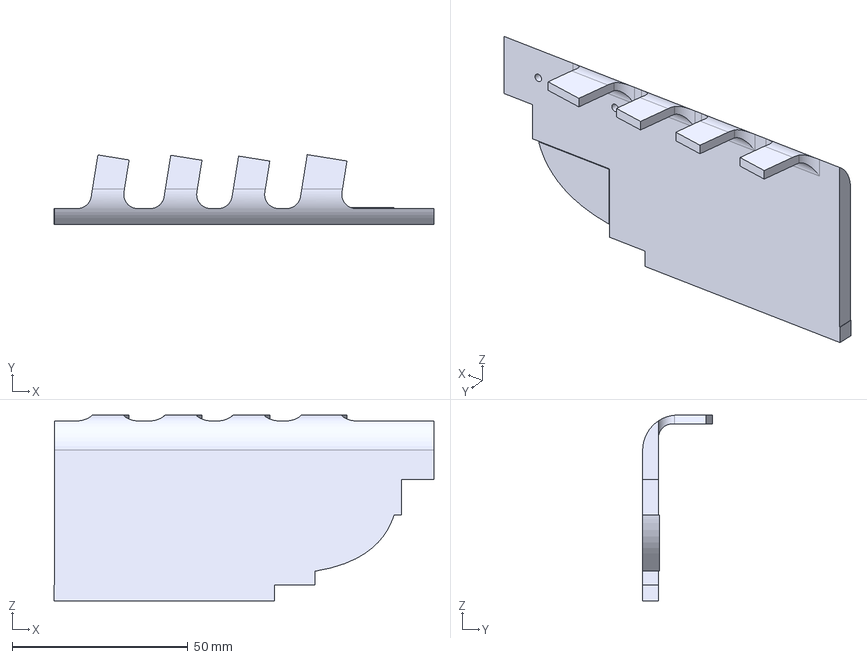
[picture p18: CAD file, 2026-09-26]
Hardware/V6_FreeCAD/v5_step/Robotic Hand_V5_simulacra - driver_side_palm_cover2.step
108.1 x 19.8 x 52.9 mm

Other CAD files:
Hardware/V6_FreeCAD/v5_step/Robotic Hand_V5_simulacra - Palm3_2.step
Hardware/V6_FreeCAD/v5_step/Robotic Hand_V5_simulacra - Metacarpal Bone_V02_pinky.step
Hardware/V6_FreeCAD/v5_step/Robotic Hand_V5_simulacra - Base Bone 1_V02.step
Hardware/V6_FreeCAD/v5_step/Robotic Hand_V5_simulacra - first_thumb_hinge.step
Hardware/V6_FreeCAD/v5_step/Robotic Hand_V5_simulacra - Base Bone 1.2_V02_ringfing.step
Hardware/V6_FreeCAD/v5_step/Robotic Hand_V5_simulacra - Base Bone 1_V02 (1).step
Hardware/V6_FreeCAD/v5_step/Robotic Hand_V5_simulacra - Base Bone 1_V02 (2).step
Hardware/V6_FreeCAD/v5_step/Robotic Hand_V5_simulacra - Base Bone 1_V02 (3).step
Hardware/V6_FreeCAD/v5_step/Robotic Hand_V5_simulacra - Distal Phalanx Bone_V02 (1).step
Hardware/V6_FreeCAD/v5_step/Robotic Hand_V5_simulacra - Distal Phalanx Bone_V02 (2).step
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

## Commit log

2026-09-26 Revise DOF motor count and build cost in README
    Updated motor count and cost estimates in README.
2026-09-26 Revise touch sensing integration details in README
    Updated README to include new touch sensing integration details and removed outdated sensor information.
2026-09-26 Add V6 FreeCAD redesign progress snapshot and README status
    - Hardware/V6_FreeCAD: the current V6 model (DexiGrab_V6.FCStd), the
    scripted FreeCAD build pipeline (one module per workstream), verification
    scripts, design notes and report, pipeline data, V5 STEP inputs and renders.
    - README: 20-motor / 20-DOF line and a V6 progress checklist.
    Electronics, the thumb-pitch motor and the V6.2 splay are still in progress
    and will follow in a later update.
    [DexiGrab_V6.FCStd, Robotic Hand_V5_simulacra - Base Bone 1.2_V02_middlefinger.step, Robotic Hand_V5_simulacra - Base Bone 1.2_V02_pinky.step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]

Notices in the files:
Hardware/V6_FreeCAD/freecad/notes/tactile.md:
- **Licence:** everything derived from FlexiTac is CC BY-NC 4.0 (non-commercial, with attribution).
